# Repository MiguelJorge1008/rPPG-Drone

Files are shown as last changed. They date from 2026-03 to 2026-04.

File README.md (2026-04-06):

# Drone rPPG

Drone-based remote vital sign monitoring system (rPPG — *remote Photoplethysmography*), using the XIAO ESP32-S3 Sense as the acquisition unit and a PC as the ground station.

<p align="center">
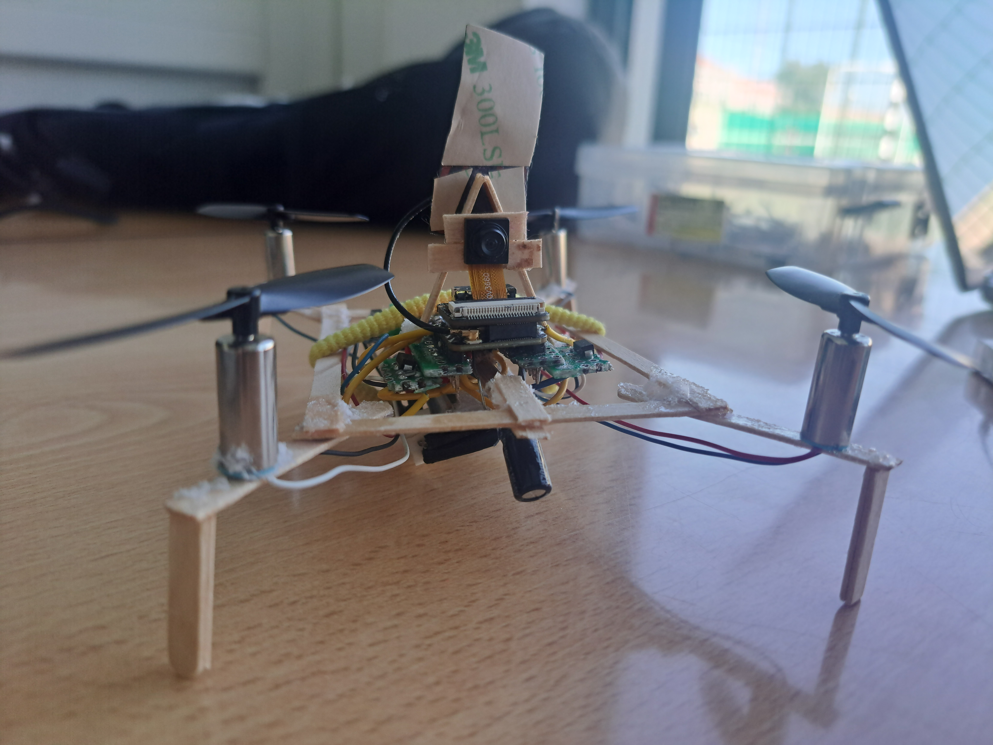
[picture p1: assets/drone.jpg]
Drone prototype
  
</p>

## Project Structure

```
Drone_rPPG/
├── firmware/                # C code (ESP-IDF) for the XIAO ESP32-S3 Sense
│   ├── main/
│   │   ├── main.c           # Wi-Fi AP, OV3660 camera, IMU, battery, HTTP/WS
│   │   ├── fc.c             # Flight controller: Mahony AHRS + cascade PID + motor mixing
│   │   ├── fc.h             # Flight controller public API
│   │   └── CMakeLists.txt
│   ├── CMakeLists.txt
│   ├── FIRMWARE.md          # Firmware technical documentation
│   ├── sdkconfig
│   └── partitions.csv
│
├── software/                # Python code (PC / Ground Station)
│   ├── main.py              # Entry point: selects mode, source, algorithm and display
│   ├── DataHandler.py       # CameraHandler, WebcamHandler, IMUHandler
│   ├── Processor.py         # FaceProcessor: forehead ROI, RGB extraction, real-time HR (rPPG)
│   ├── RespiratoryProcessor.py  # RespiratoryProcessor: pose tracking, real-time RR
│   ├── ROIExtraction.py     # Forehead ROI polygon with EMA smoothing
│   ├── SOFTWARE.md          # Software technical documentation
│   ├── algoritmos/
│   │   ├── green.py         # GREEN algorithm (Verkruysse 2008)
│   │   ├── omit.py          # OMIT algorithm (Face2PPG, Casado 2023)
│   │   ├── pos_wang.py      # POS algorithm (Wang et al. 2017)
│   │   └── adaptive_lms.py  # Adaptive LMS filter with IMU (motion cancellation)
│   └── test/
│       ├── RecordPPG.py     # Record rPPG + hardware PPG simultaneously → CSV
│       ├── RecordResp.py    # Record RR + hardware respiration sensor → CSV
│       ├── ComputeMetrics.py  # Compute HR/HRV/RR metrics → data_processed/
│       ├── Evaluate.py      # Offline evaluation: MAE±SD per algorithm
│       ├── RunTest.py       # Full pipeline: ComputeMetrics → Evaluate
│       ├── Arduino/
│       │   └── SensorIntegration.ino  # Arduino: PPG + resp sensors → Serial 115200
│       ├── data/            # Raw CSV recordings (signal only)
│       ├── data_processed/  # Processed CSVs with computed metrics
│       └── results/         # Evaluation plots (PNG)
│
├── assets/                  # Project images
└── README.md
```

## Hardware

| Component | Model | Notes |
|---|---|---|
| MCU | Seeed Studio XIAO ESP32-S3 Sense | 8 MB PSRAM + 8 MB Flash |
| Camera | OV3660 | QVGA 320×240, ~25 FPS, MJPEG |
| IMU | MPU-6050 | I2C, 500 Hz, ±16 g / ±2000°/s |
| Motors | 4× brushed DC | LEDC PWM 15 kHz, 8-bit (GPIO 2/3/4/7) |
| Battery | LiPo 1S | ADC monitoring on GPIO 1 |

## Firmware

Developed with **ESP-IDF v5.5.3**. The firmware runs on the ESP32-S3 and is responsible for:

- Creating a Wi-Fi AP network (`rPPG-Drone`, `192.168.4.1`)
- Capturing and serving the OV3660 camera **MJPEG stream** (port 81)
- Exposing IMU data and estimated attitude via **HTTP `/imu`** (port 80)
- Flight control via **flight controller** in `fc.c` (Mahony AHRS + cascade PID, 500 Hz, Core 1)
- Battery monitoring with deep sleep protection

> **Important:** AWB, AGC and AEC are **intentionally disabled**. Automatic sensor controls suppress the subtle skin color variations that make up the rPPG signal.

### Build and Flash

```bash
cd firmware
idf.py build flash monitor
```

### Flight Control

The web page at `http://192.168.4.1` includes a virtual joystick (WebSocket at 20 Hz) and ARM/DISARM buttons. See [FIRMWARE.md](firmware/FIRMWARE.md) for full details.

## Software (PC)

Developed in **Python 3.11** with OpenCV, MediaPipe and NumPy/SciPy.

| Module | Function |
|---|---|
| `main.py` | Selects mode (rPPG / Respiratory), source, algorithm and display mode at startup |
| `DataHandler.py` | `CameraHandler` (MJPEG), `WebcamHandler` (webcam), `IMUHandler` (polling `/imu`) |
| `Processor.py` | FaceMesh → forehead ROI → RGB/frame → real-time HR via peak detection (30 s window) |
| `RespiratoryProcessor.py` | Bartula 2013: chest ROI → 1D profile cross-correlation → real-time RR |
| `ROIExtraction.py` | Forehead polygon (4 landmarks) with EMA smoothing |
| `algoritmos/green.py` | Direct green channel |
| `algoritmos/omit.py` | QR decomposition, orthogonal subspace |
| `algoritmos/pos_wang.py` | 1.6 s sliding window, POS projection |
| `algoritmos/adaptive_lms.py` | Adaptive NLMS with IMU as noise reference (drone only) |
| `test/RecordPPG.py` | Simultaneous rPPG + hardware PPG recording → CSV |
| `test/RecordResp.py` | Simultaneous RR + hardware respiration sensor recording → CSV |
| `test/ComputeMetrics.py` | Post-process raw CSVs → metrics CSVs in `data_processed/` |
| `test/Evaluate.py` | MAE±SD per algorithm from `data_processed/`; plots to `results/` |
| `test/RunTest.py` | Full pipeline: ComputeMetrics → Evaluate |
| `test/Arduino/SensorIntegration.ino` | Arduino: reads PPG + respiration sensors, streams over Serial at 115200 baud |

### Run

```bash
cd software
pip install opencv-python mediapipe requests numpy scipy matplotlib pandas
python main.py
```

The program prompts for:
1. Mode: `1` rPPG · `2` Respiratory
2. Display: `1` graphs + camera window · `2` terminal only (higher FPS)
3. Video source: `A` drone · `B` webcam
4. *(rPPG only)* Algorithm: GREEN, OMIT, POS_WANG, LMS

Press `q` to stop.

| Mode | Measures | Method |
|---|---|---|
| **rPPG** | Heart rate (BPM) | FaceMesh → forehead ROI → colour signal → peak detection |
| **Respiratory** | Breathing rate (RPM) | Bartula 2013 — chest ROI cross-correlation, no landmarks |

### Record and Evaluate

<p align="center">
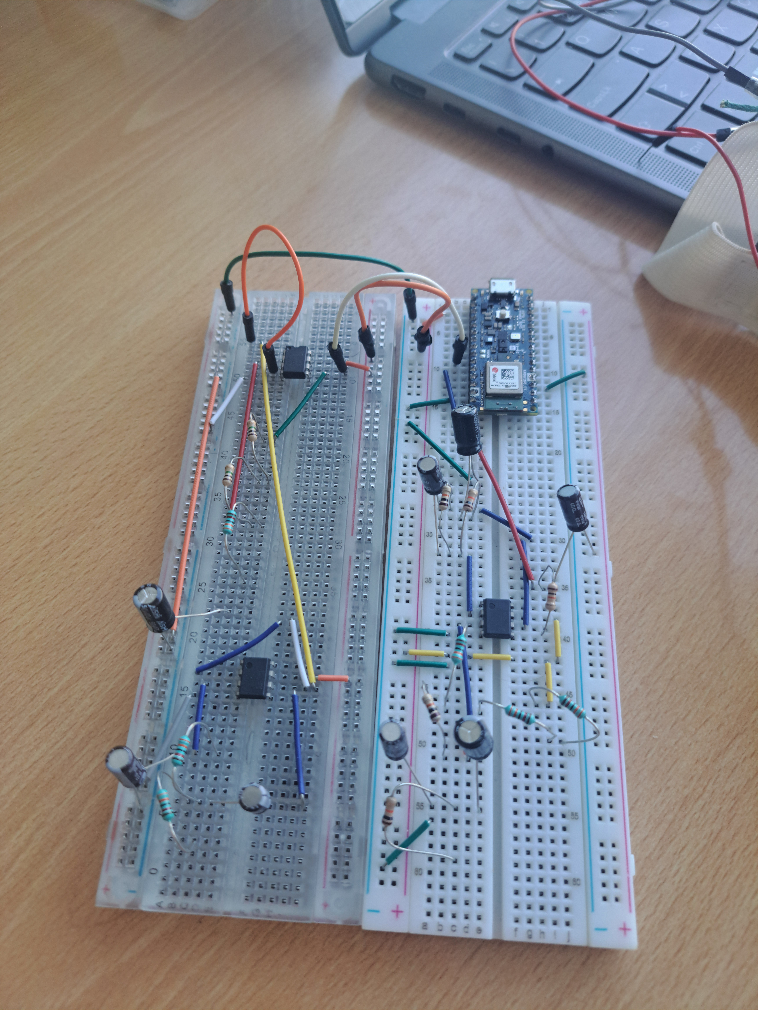
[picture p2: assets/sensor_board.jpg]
Arduino sensor board (PPG + respiration)
  
</p>

```bash
# From software/test/
python RecordPPG.py    # rPPG + hardware PPG  → data/BVP_<ALGO>_<ts>_{sw,hw}.csv
python RecordResp.py   # RR  + hardware resp  → data/RESP_<ts>_{sw,hw}.csv

# Run full evaluation pipeline
python RunTest.py
```

`RunTest.py` runs in two steps:

1. **`ComputeMetrics.py`** — reads raw signals from `data/`, computes HR/HRV/RR metrics via peak detection, writes processed CSVs to `data_processed/`
2. **`Evaluate.py`** — reads `data_processed/`, interpolates hardware GT onto software timestamps, prints per-algorithm MAE±SD tables and saves plots to `results/`

```
Table 1 — Rate: standard algorithms (MAE ± SD)
  HR:  GREEN · OMIT · POS_WANG
  RR:  BARTULA

Table 2 — Rate: motion/IMU compensation (MAE ± SD)
  GREEN (with IMU) · LMS

Table 3 — HRV + RRV: standard algorithms (MAE ± SD)
  SDNN / RMSSD (ms):  GREEN · OMIT · POS_WANG
  BBI (s):            BARTULA

Table 4 — HRV: motion/IMU compensation (MAE ± SD)
  GREEN (with IMU) · LMS
```

Tables 2 and 4 only appear when IMU/LMS recordings are present.

## How It Works

**rPPG mode (heart rate):**
```
OV3660 (MJPEG)  ──→  CameraHandler  ──→  FaceProcessor
MPU-6050        ──→  IMUHandler     ──┘
                                         │
                                    FaceMesh (468 landmarks)
                                         │
                                    Forehead ROI (4 landmarks)
                                         │
                                   Mean RGB / frame
                                         │
                              GREEN / OMIT / POS / LMS
                                         │
                              Detrend + Butterworth [0.75–4 Hz]
                                         │
                               find_peaks → BPM (30 s window)
```

**Respiratory mode (breathing rate) — Bartula et al. 2013:**
```
OV3660 (MJPEG)  ──→  CameraHandler  ──→  RespiratoryProcessor
                                         │
                                 ┌── STARTUP (once) ──┐
                                 │  MediaPipe Pose     │
                                 │  detect shoulders   │
                                 │  → chest ROI (px)  │
                                 │  close Pose         │
                                 └────────────────────┘
                                         │
                                   Fixed chest ROI
                                         │
                           1D vertical profile (mean + std / row)
                           High-pass (removes illumination drift)
                                         │
                           Phase cross-correlation (Hann window)
                           r = F⁻¹( F(pₜ) · conj(F(pₜ₋₁)) )
                           Sub-pixel peak → frame shift
                                         │
                           Integrate shifts → chest position signal
                                         │
                           Global motion detector (block-based)
                                         │
                           Detrend + Butterworth [0.1–0.5 Hz]
                                         │
                           find_peaks → breath-by-breath validation
                           (exclude motion segments, invalid durations)
                                         │
                           Median inter-breath interval → RPM
```

See [FIRMWARE.md](firmware/FIRMWARE.md) and [SOFTWARE.md](software/SOFTWARE.md) for detailed documentation.

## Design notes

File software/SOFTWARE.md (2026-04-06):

# Drone rPPG — Software

Video acquisition and face detection software for rPPG (remote Photoplethysmography) signal extraction from a drone equipped with a XIAO ESP32-S3 camera.

---

## File Structure

```
software/
├── main.py                      # Entry point: selects mode, source, algorithm and display
├── DataHandler.py               # CameraHandler, WebcamHandler, IMUHandler
├── Processor.py                 # FaceProcessor: forehead ROI, RGB extraction, real-time HR (rPPG)
├── RespiratoryProcessor.py      # RespiratoryProcessor: pose tracking, real-time RR
├── ROIExtraction.py             # Forehead polygon (4 landmarks) with EMA smoothing
├── algoritmos/
│   ├── green.py                 # GREEN algorithm (Verkruysse 2008)
│   ├── omit.py                  # OMIT algorithm (Casado 2023)
│   ├── pos_wang.py              # POS algorithm (Wang et al. 2017)
│   └── adaptive_lms.py          # Adaptive NLMS filter with IMU (drone only)
└── test/
    ├── RecordPPG.py             # Record rPPG + hardware PPG simultaneously → CSV
    ├── RecordResp.py            # Record RR + hardware respiration sensor → CSV
    ├── ComputeMetrics.py        # Post-process raw CSVs → metrics CSVs in data_processed/
    ├── Evaluate.py              # Offline evaluation: MAE±SD per algorithm; plots to results/
    ├── RunTest.py               # Runs the full pipeline: ComputeMetrics → Evaluate
    ├── Arduino/
    │   └── SensorIntegration.ino    # Arduino: PPG + respiration sensors → Serial (115200 baud)
    ├── data/                    # Raw CSV recordings (timestamp + signal only)
    ├── data_processed/          # Processed CSVs with computed metrics
    └── results/                 # Evaluation plots (PNG)
```

---

## rPPG Pipeline

```
Frame (camera / webcam)
  → MediaPipe FaceMesh (face detection)
  → Forehead ROI (4 landmarks → forehead polygon → mean RGB/frame)
  → rgb_signal (N, 3)
  → [GREEN / OMIT / POS_WANG / LMS]  →  raw BVP (N,)
  → apply_filters  →  filtered BVP (N,)
  → estimate_hr  →  BPM  (find_peaks, 30 s window)
```

---

## Files

### `main.py`

Entry point. Prompts the user for the operating mode, display preference, video source and rPPG algorithm, then starts the main loop.

**Startup prompts (in order):**

| Step | Options | Description |
|---|---|---|
| Mode | `1` rPPG · `2` Respiratory | `FaceProcessor` or `RespiratoryProcessor` |
| Display | `1` Yes · `2` No | Show matplotlib graphs + camera window, or terminal only |
| Source | `A` Drone · `B` Webcam | MJPEG stream or local webcam |
| Algorithm | `1`–`4` *(rPPG only)* | GREEN, OMIT, POS_WANG, LMS |

- **Display mode 2 (terminal only)** skips all `matplotlib` and `cv2.imshow` calls, significantly increasing FPS by eliminating rendering overhead.
- **Source A — Drone:** `CameraHandler` (MJPEG stream) + `IMUHandler` (polling `/imu`, rPPG mode only); fixed IP `http://192.168.4.1`
- **Source B — Webcam:** `WebcamHandler` (local OpenCV VideoCapture)

---

### `DataHandler.py`

Three data acquisition classes.

**Class: `CameraHandler`** — MJPEG stream from the drone camera

| Method | Description |
|---|---|
| `__init__(base_url)` | Opens the connection and starts the capture thread |
| `update()` | Continuous thread that reads the MJPEG stream, extracts JPEG frames and stores the latest one |
| `get_frame()` | Returns the latest captured frame (`None` if not yet available) |
| `stop()` | Stops the capture thread |

**Technical details:**
- Stream read via `requests` with `stream=True`
- JPEG frames extracted from the binary buffer using `0xFF 0xD8` (start) and `0xFF 0xD9` (end) markers
- Separate daemon thread with automatic reconnection (2 s retry)
- Stream URL: `http://<IP>:81/stream`

**Class: `WebcamHandler`** — local webcam (PC)

| Method | Description |
|---|---|
| `__init__()` | Opens `cv2.VideoCapture(0)` and starts capture thread |
| `get_frame()` | Returns the latest captured frame |
| `stop()` | Releases the VideoCapture |

**Class: `IMUHandler`** — drone IMU data via HTTP

| Method | Description |
|---|---|
| `__init__(base_url)` | Starts a polling thread to the `/imu` endpoint at 10 Hz |
| `get_imu()` | Returns the latest JSON sample or `None` |
| `stop()` | Stops the thread |

JSON fields: `ax, ay, az` (g), `gx, gy, gz` (°/s), `bat` (mV), `fc_state`.

---

### `ROIExtraction.py`

Forehead ROI polygon extraction with EMA smoothing.

**Constant:**

| Constant | Value | Description |
|---|---|---|
| `ROI_FOREHEAD` | `"FOREHEAD"` | 4-landmark forehead quadrilateral |

**Landmark indices:**

- `FOREHEAD_ROI = [103, 332, 296, 66]` — 4 forehead landmarks (MediaPipe FaceMesh)

**Function:**

| Function | Description |
|---|---|
| `get_roi_polygon(landmarks, w, h, ema, alpha)` | Returns forehead polygon with EMA smoothing (`alpha=0.35`) |

---

### `Processor.py`

Processes frames with MediaPipe FaceMesh, extracts the forehead RGB signal, runs rPPG algorithms and estimates HR in real time.

**Class: `FaceProcessor`**

| Method | Description |
|---|---|
| `__init__(camera, imu, algo, display)` | Initializes FaceMesh, signal buffers, background threads; `display=False` disables all rendering |
| `process_frame(frame)` | Resizes to 320×240, runs FaceMesh, extracts forehead ROI RGB, draws overlay |
| `get_fps(window=60)` | Estimates FPS from real timestamps; fallback 27.0 Hz |
| `apply_filters(bvp, fs)` | Detrend + Butterworth bandpass [0.75–4.0 Hz] |
| `estimate_hr(bvp, fs)` | `find_peaks` on filtered BVP → mean RRI → BPM |
| `_estimate_hr_realtime()` | Computes BVP + HR on last 30 s of signal |
| `_compute_hr_background()` | Background thread: HR every 30 frames |
| `run()` | Main acquisition + display loop |
| `stop()` | Closes FaceMesh and camera |

**FaceMesh configuration:**
- `max_num_faces=1`, `refine_landmarks=False`
- `min_detection_confidence=0.5`, `min_tracking_confidence=0.5`

**Filters (`apply_filters`):**

1. **Detrend** (λ=100) — removes slow baseline drift (Tarvainen sparse method)
2. **Butterworth bandpass** [0.75–4.0 Hz], order 2, `filtfilt` — cardiac band (45–240 bpm)

**HR estimation (`estimate_hr`):**

`find_peaks` with `distance=0.5 s` and `prominence=0.25×std`; RRI filter [0.4–1.5 s]; HR = 60 / mean(RRI). Consistent with `ComputeMetrics.metrics_from_peaks`.

**Background thread trigger:**

| Trigger | Interval | Task |
|---|---|---|
| Every 30 frames | ~2 s @ 15 fps | HR estimation |

---

### `RespiratoryProcessor.py`

Estimates respiratory rate (RR) in real time using the **Bartula (2013)** camera-based algorithm. Uses MediaPipe Pose **once at startup** to locate the chest and derive a tight ROI; Pose is then closed and the Bartula algorithm runs on that fixed ROI for the rest of the session.

> Bartula, M., Tigges, T., & Muehlsteff, J. *Camera-based System for Contactless Monitoring of Respiration.* IEEE EMBS, 2013.

**Class: `RespiratoryProcessor`**

| Method | Description |
|---|---|
| `__init__(camera, display)` | Initialises signal buffers, position integrator and background thread state |
| `_init_roi_from_pose(timeout)` | Runs Pose on live frames until shoulders detected; computes chest ROI; closes Pose |
| `process_frame(frame)` | Extracts profile, computes shift, integrates position, detects global motion |
| `get_fps(window=60)` | Estimates FPS from recent timestamps; fallback 25.0 Hz |
| `_make_profile(roi_gray)` | 1D vertical profile: mean+std per row, high-pass filtered |
| `_profile_shift(p_curr, p_prev)` | Phase cross-correlation with Hann window; sub-pixel quadratic interpolation |
| `_global_motion(curr, prev)` | Block-based frame-difference motion detector |
| `apply_filters(sig, fs)` | Linear detrend + Butterworth bandpass [0.1–0.5 Hz] |
| `_estimate_rr_from_peaks(filtered, fs, flags)` | Peak detection + breath-by-breath validation |
| `_compute_rr_background()` | Background thread: RR every 30 frames |
| `run()` | Calls `_init_roi_from_pose`, then main acquisition + display loop |
| `stop()` | Stops camera and closes windows |

**Bartula pipeline (per frame):**

```
Frame ROI (grayscale)
  → _make_profile       : mean(row) + std(row) → high-pass → 1D vector (H,)
  → _profile_shift      : Hann window → FFT cross-correlation → sub-pixel peak
                          r = F⁻¹( F(pₜ) · conj(F(pₜ₋₁)) )
  → integrate shift     : position += shift  (chest displacement signal)
  → _global_motion      : block diff > MOTION_THRESH → flag frame
  → apply_filters       : detrend + Butterworth [0.1–0.5 Hz]
  → _estimate_rr_from_peaks : find_peaks → validate each breath interval
                              (duration ∈ [1.5, 10] s, motion_ratio < 0.5)
  → median(valid intervals) → rpm → EMA → rr_estimate
```

**Parameters:**

| Constant | Value | Description |
|---|---|---|
| `ROI_PAD_X_FACTOR` | 0.15 | Horizontal ROI padding as fraction of shoulder width |
| `ROI_HEIGHT_FACTOR` | 1.20 | Estimated chest height as fraction of shoulder width (no hips) |
| `ROI_TOP_FACTOR` | 0.10 | ROI top margin above shoulder line |
| `HP_KERNEL` | 21 | Moving-average kernel for profile high-pass |
| `BLOCK_SIZE` | 16 px | Block size for motion detector |
| `MOTION_THRESH` | 12 | Mean abs diff threshold per block |
| `GLOBAL_MOTION_RATIO` | 0.30 | Moving-block fraction to flag global motion |
| `MIN_SEC` | 20 s | Minimum signal window before first estimate |
| `RR_ALPHA` | 0.15 | EMA smoothing factor |
| `MIN_BREATH_S` | 1.5 s | Shortest valid breath (≈ 40 rpm) |
| `MAX_BREATH_S` | 10.0 s | Longest valid breath (6 rpm) |

---

### `test/`

Hardware-synchronized recording and evaluation scripts.

**`Arduino/SensorIntegration.ino`** — Arduino sketch that reads an analog PPG sensor (pin `A6`) and a respiration sensor (pin `A5`) and streams timestamped samples over Serial at 115200 baud.

---

**`RecordPPG.py`** — Records rPPG and hardware PPG simultaneously and saves to CSV.

- **Warmup:** 30 s (no data saved); **Recording:** 60 s
- Outputs to `data/`:
  - `BVP_<ALGO>_<ts>_sw.csv` — `timestamp`, `signal_sw` (z-normalised BVP)
  - `BVP_<ALGO>_<ts>_hw.csv` — `timestamp`, `signal_hw` (raw PPG, relative time)
  - `BVP_<ALGO>_<ts>_sw_IMU.csv` / `_hw_IMU.csv` — same format, suffix `_IMU` indicates motion recording (used in Table 2 / Table 4 evaluation)
- HW signal read via Serial (Arduino, `COM3`, 115200 baud)

---

**`RecordResp.py`** — Records respiratory rate and hardware respiration sensor simultaneously and saves to CSV.

- **Warmup:** 20 s; **Recording:** 60 s
- Outputs to `data/`:
  - `RESP_<ts>_sw.csv` — `timestamp`, `signal_sw`
  - `RESP_<ts>_hw.csv` — `timestamp`, `signal_hw`

---

**`ComputeMetrics.py`** — Post-processes raw CSVs from `data/` into metric CSVs in `data_processed/`.

```bash
python ComputeMetrics.py                             # all pairs in data/
python ComputeMetrics.py --file BVP_GREEN_X_sw.csv  # single pair
```

**rPPG processing (`process_pair`):**
- SW: cumulative expanding window; `metrics_from_peaks` → HR, SDNN, RMSSD per timestamp
- HW: same, with bandpass filter [0.75–4.0 Hz] applied first
- Supports `_IMU` suffix: `BVP_<ALGO>_<ts>_sw_IMU.csv` → `BVP_<ALGO>_<ts>_sw_IMU_processed.csv`
- Outputs:
  - `BVP_<ALGO>_<ts>_sw[_IMU]_processed.csv` — `timestamp`, `signal_sw`, `HR_<algo>`, `SDNN_<algo>`, `RMSSD_<algo>`
  - `BVP_<ALGO>_<ts>_hw[_IMU]_processed.csv` — `timestamp`, `signal_hw`, `HR_gt`, `SDNN_gt`, `RMSSD_gt`

**Respiratory processing (`process_resp_pair`):**
- SW downsampled to 25 Hz before loop (avoids O(n²) at high acquisition rates)
- Sliding 30 s window; `resp_metrics_from_peaks` → RR, BBI per timestamp
- Outputs:
  - `RESP_<ts>_sw_processed.csv` — `timestamp`, `signal_sw`, `RR_BARTULA`, `BBI_BARTULA`
  - `RESP_<ts>_hw_processed.csv` — `timestamp`, `signal_hw`, `RR_gt`, `BBI_gt`

**Peak detection (`metrics_from_peaks`):**
- `find_peaks` with `distance=0.5 s`, `prominence=0.25×std`
- RRI filter: [0.4–1.5 s]; HR = 60 / mean(RRI); SDNN = std(RRI)×1000; RMSSD = √mean(ΔRRI²)×1000

**Peak detection (`resp_metrics_from_peaks`):**
- `find_peaks` with `distance=1.5 s`, `prominence=0.25×std`
- BBI filter: [1.5–10.0 s]; RR = 60 / mean(BBI)

---

**`Evaluate.py`** — Offline evaluation. Reads processed CSVs from `data_processed/`, interpolates HW ground truth onto SW timestamps, and computes MAE±SD per algorithm.

```bash
python Evaluate.py               # all recordings in data_processed/
python Evaluate.py --file BVP_GREEN_X_sw_processed.csv  # single file
```

**Warmup cutoff:**

| Recording type | Cutoff | Reason |
|---|---|---|
| rPPG (HR_*) | 30 s | Matches the 30 s minimum window in `FaceProcessor._estimate_hr_realtime` |
| Respiratory (RR_BARTULA) | 20 s | Matches `MIN_SEC = 20` in `RespiratoryProcessor` |

**GT interpolation:** HW metrics (on HW timestamps) are linearly interpolated onto SW timestamps before computing error metrics.

**Metrics:** MAE ± SD only.

**Output — four tables:**

| Table | Content |
|---|---|
| Table 1 — Rate: standard algorithms | MAE±SD for HR (GREEN, OMIT, POS_WANG) and RR (BARTULA) |
| Table 2 — Rate: motion/IMU compensation | MAE±SD for GREEN (with IMU) and LMS |
| Table 3 — HRV + RRV: standard algorithms | SDNN, RMSSD (ms) and BBI (s) MAE±SD per algorithm |
| Table 4 — HRV: motion/IMU compensation | SDNN and RMSSD MAE±SD for GREEN (with IMU) and LMS |

Tables 2 and 4 only appear when IMU/LMS recordings are present.

**Summary CSV:** `results/csv_raw/summary_metrics.csv` — all per-file results in tabular form.

**Plots:** 3-subplot figure per recording (signals + peaks, rate over time, HRV/IBI over time), cropped to 0–60 s; saved to `results/`.

---

**`RunTest.py`** — Runs the full pipeline in order:

```bash
python RunTest.py
```

1. `ComputeMetrics.py` → `data_processed/`
2. `Evaluate.py` → prints tables + saves plots to `results/`

---

**Common configuration** (top of each recording script):

| Constant | Default | Description |
|---|---|---|
| `SERIAL_PORT` | `COM3` | Serial port of the Arduino |
| `BAUD_RATE` | `115200` | Must match `SensorIntegration.ino` |
| `XIAO_IP` | `http://192.168.4.1` | Drone IP (ignored when using webcam) |
| `WARMUP_S` | 30 (PPG) / 20 (Resp) | Warmup duration before recording starts |
| `RECORD_S` | 60 | Recording duration |

---

### `algoritmos/`

Each algorithm receives `rgb (N, 3)` (and optionally `fs` or `imu`) and returns `bvp (N,)` — raw BVP signal, without filters.

#### `green.py` — GREEN

> Verkruysse, W., Svaasand, L. O. & Nelson, J. S. *Remote plethysmographic imaging using ambient light.* Optical Express 16, 21434–21445 (2008).

Extracts the green channel directly. Hemoglobin absorbs strongly in the green band (~550 nm), making it the channel with the highest pulse amplitude.

```
BVP = G
```

---

#### `omit.py` — OMIT (Orthogonal Matrix Image Transformation)

> Álvarez Casado, C., & Bordallo López, M. *Face2PPG: An unsupervised pipeline for blood volume pulse extraction from faces.* IEEE JBHI (2023).

Uses QR decomposition to remove the dominant component of the RGB signal and extract the pulse in the orthogonal subspace. Robust to video compression artifacts.

```
A = rgb.T                    # (3, N)
Q, R = qr(A)
S = Q[:, 0]                  # dominant direction
P = I - Sᵀ·S                 # orthogonal projector
Y = P @ A
BVP = Y[1, :]
```

---

#### `pos_wang.py` — POS (Plane-Orthogonal-to-Skin)

> Wang, W., den Brinker, A. C., Stuijk, S., & de Haan, G. *Algorithmic principles of remote PPG.* IEEE TBME, 64(7), 1479–1491 (2017).

1.6 s sliding window. Temporally normalizes RGB and projects onto a plane orthogonal to the skin tone to separate pulse from intensity variations.

```
l = ceil(1.6 × fs)
Cn = RGB[m:n] / mean(RGB[m:n])
S = [[0,1,-1],[-2,1,1]] @ Cn
h = S[0] + σ(S[0])/σ(S[1]) × S[1]
H[m:n] += h - mean(h)           # overlap-add
```

---

#### `adaptive_lms.py` — Adaptive LMS with IMU

> Widrow, B. & Hoff, M. E. *Adaptive switching circuits.* IRE WESCON (1960).

Cancels motion artifacts using the IMU signal as noise reference. NLMS filtering adapts its weights to estimate and subtract the motion component from the green signal.

```
green = rgb[:, 1]
imu_ref = interp(IMU, N)
error[n] = green[n] - w·x[n]
w += (μ / (||x||² + ε)) × error × x   # NLMS weight update
```

**Parameters:** `μ=0.1`, `ε=1e-3`. Drone mode only.

---

## Dependencies

```
opencv-python
mediapipe
requests
numpy
scipy
matplotlib
pandas
```

Install:
```bash
pip install opencv-python mediapipe requests numpy scipy matplotlib pandas
```

> Requires **Python 3.11** (MediaPipe has limited compatibility with newer versions)

---

## How to Run

```bash
python main.py
```

The program prompts:
1. Mode: `1` rPPG · `2` Respiratory
2. Display: `1` graphs + camera · `2` terminal only (higher FPS)
3. Video source: `A` (drone, `192.168.4.1`) or `B` (PC webcam)
4. *(rPPG only)* Algorithm: `1` GREEN · `2` OMIT · `3` POS_WANG · `4` LMS

Press `q` to stop.

### Record and evaluate

```bash
# Record (run from test/)
python RecordPPG.py    # rPPG + hardware PPG  → data/BVP_<ALGO>_<ts>_{sw,hw}.csv
python RecordResp.py   # RR  + hardware resp  → data/RESP_<ts>_{sw,hw}.csv

# Evaluate all recordings
python RunTest.py
```

---

## Status and Next Steps

- [x] MJPEG stream from XIAO ESP32 camera
- [x] Face detection with MediaPipe FaceMesh (468 landmarks)
- [x] Forehead ROI (4 landmarks, EMA-smoothed polygon)
- [x] GREEN, OMIT, POS_WANG and LMS algorithms
- [x] Filters: detrend + Butterworth bandpass [0.75–4.0 Hz]
- [x] Real-time HR via find_peaks (every 30 frames, 30 s window)
- [x] LMS motion artifact cancellation with IMU
- [x] Respiratory rate via MediaPipe Pose (thorax movement, 0.1–0.5 Hz)
- [x] Display toggle: full visual mode vs terminal-only (improved FPS)
- [x] Hardware-synchronized recording scripts (RecordPPG, RecordResp)
- [x] ComputeMetrics: peak-based HR/HRV/RR metrics → data_processed/
- [x] Evaluate: MAE±SD per algorithm, GT interpolation, plots to results/
- [x] Consistent peak-based HR estimation across real-time and offline evaluation
- [ ] IMU-based motion compensation for GREEN / OMIT / POS
- [ ] Clinical validation against oximeter ground truth

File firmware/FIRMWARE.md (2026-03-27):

# Firmware — Drone rPPG (XIAO ESP32-S3 Sense)

Firmware for MJPEG video capture over Wi-Fi with the OV3660 sensor and brushed motor flight control, optimized for **rPPG (Remote Photoplethysmography)** on a drone.

---

## Hardware

| Component | Model |
|---|---|
| MCU | Seeed Studio XIAO ESP32-S3 Sense |
| Camera | OV3660 (QQVGA 160×120, ~25 FPS, MJPEG) |
| IMU | MPU-6050 (I2C, 500 Hz, ±16 g / ±2000°/s) |
| Motors | 4× brushed DC (LEDC PWM 15 kHz, 8-bit) |
| Battery | LiPo 1S (ADC monitoring GPIO 1) |
| PSRAM | 8 MB (Octal) |
| Flash | 8 MB |
| Framework | ESP-IDF v5.5.3 |

---

## Network

The firmware operates in **Access Point (AP) mode** — the ESP32 creates its own Wi-Fi network.

| Parameter | Value |
|---|---|
| SSID | `rPPG-Drone` |
| Password | `12345678` |
| Fixed IP | `192.168.4.1` |
| Channel | 2 (2.4 GHz) |
| Security | WPA2-PSK |

---

## Quick Start

1. Build and flash:
```bash
idf.py build flash monitor
```

2. Connect your PC/phone to the `rPPG-Drone` network (password: `12345678`)

3. Open a browser at `http://192.168.4.1`

---

## HTTP Endpoints

There are **two HTTP servers**:
- **Port 80** — HTML page, controls, IMU, flight
- **Port 81** — MJPEG stream (dedicated server, does not block other endpoints)

| URL | Method | Server | Description |
|-----|---|---|---|
| `/` | GET | :80 | HTML page with stream + camera, flight and PID controls |
| `/stream` | GET | :81 | Continuous MJPEG stream |
| `/control?aec=X&gain=Y` | GET | :80 | Adjust exposure and gain at runtime |
| `/imu` | GET | :80 | JSON with raw IMU, estimated attitude, battery and FC state |
| `/cmd?state=arm\|disarm` | GET | :80 | Arm/disarm the flight controller |
| `/cmd?roll=&pitch=&yaw=&thrust=` | GET | :80 | Manual flight setpoint |
| `/pid[?att_kp=&...]` | GET | :80 | Read or update PID gains at runtime |
| `/ws` | WS | :80 | WebSocket for joystick setpoints at 20 Hz |

### `/control` Parameters

| Parameter | Range | Description |
|---|---|---|
| `aec` | 0 – 1200 | Manual exposure time (OV3660) |
| `gain` | 0 – 30 | Manual analog gain |

### `/imu` Response

```json
{
  "ax": 0.01, "ay": -0.02, "az": 0.99,
  "gx": 10.5, "gy": -5.2, "gz": 0.1,
  "roll": 1.2, "pitch": -0.8, "yaw": 45.0,
  "bat": 3850,
  "fc_state": "disarmed"
}
```

| Field | Unit | Description |
|---|---|---|
| `ax`, `ay`, `az` | g | Linear acceleration (±16 g, 2048 LSB/g) |
| `gx`, `gy`, `gz` | deg/s | Angular velocity (±2000°/s, 16.4 LSB/°/s) |
| `roll`, `pitch`, `yaw` | degrees | Attitude estimated by Mahony AHRS |
| `bat` | mV | Battery voltage (100K+100K divider, GPIO1) |
| `fc_state` | string | `"disarmed"` or `"flight"` |

### `/cmd` Parameters

| Parameter | Range | Description |
|---|---|---|
| `state` | `arm` / `disarm` | FC state transition |
| `roll` | −30 – +30 | Desired roll angle (degrees) |
| `pitch` | −30 – +30 | Desired pitch angle (degrees) |
| `yaw` | −200 – +200 | Desired yaw rate (°/s) |
| `thrust` | 0.0 – 1.0 | Normalized base thrust |

### `/pid` Parameters

GET without query → returns JSON with current gains.
GET with query → applies new gains and returns confirmed values.

| Parameter | Description | Default |
|---|---|---|
| `att_kp` | Outer loop kp (roll = pitch) | 3.5 |
| `att_ki` | Outer loop ki | 2.0 |
| `rr_kp/ki/kd` | Rate roll kp/ki/kd | 70 / 0 / 0 |
| `rp_kp/ki/kd` | Rate pitch kp/ki/kd | 70 / 0 / 0 |
| `ry_kp/ki/kd` | Rate yaw kp/ki/kd | 50 / 0 / 0 |

### WebSocket `/ws`

The client sends JSON at 20 Hz:
```json
{"r": 5.0, "p": -3.0, "y": 10.0, "t": 0.55}
```

| Field | Unit | Description |
|---|---|---|
| `r` | degrees | Roll (−30 to +30) |
| `p` | degrees | Pitch (−30 to +30) |
| `y` | °/s | Yaw rate (−200 to +200) |
| `t` | 0.0 – 1.0 | Thrust |

Each WS frame resets the FC watchdog. If no frames arrive for **500 ms**, the FC automatically transitions to `DISARMED`.

---

## Flight Controller

The flight controller is implemented in `main/fc.c` + `main/fc.h` and runs in a dedicated FreeRTOS task on **Core 1** at **500 Hz** (priority 8).

### Architecture

```
MPU-6050 (500 Hz)
    │
    ▼
Mahony AHRS  →  Euler angles (roll, pitch, yaw)
    │
    ▼
Outer PID (attitude)  →  rate setpoint
    │
    ▼
Inner PID (rate)  →  torques (roll, pitch, yaw)
    │
    ▼
Motor mixing  →  M1/M2/M3/M4 duties (0–255)
```

**Sensor fusion:** Mahony AHRS (ported from `sensfusion6.c` — Crazyflie / ESP-Drone).
**PID:** Cascade rate/attitude (ported from `pid.c` — Crazyflie / ESP-Drone).

### FC States

| State | Description |
|---|---|
| `FC_DISARMED` | Motors off, PIDs reset |
| `FC_FLIGHT` | PID active, accepts setpoints via `/cmd` or `/ws` |

### Safety

| Mechanism | Value | Behavior |
|---|---|---|
| Setpoint watchdog | 500 ms | FC transitions to DISARMED if no setpoint received |
| Tilt protection | ±50° | FC transitions to DISARMED if roll or pitch exceeds limit |
| Mahony warmup | 2 s | Motors locked at boot for AHRS convergence |
| Critical battery | < 3100 mV | FC transitions to DISARMED + deep sleep |

### Motor Mixing (quadrotor X)

```
M1 (front-left, CW)  |  M2 (front-right, CCW)
─────────────────────────────────────────────
M4 (back-left, CCW)  |  M3 (back-right, CW)
```

| Motor | GPIO | Rotation | LEDC Channel |
|---|---|---|---|
| M1 (front-left) | GPIO 2 | CW | CH1 |
| M2 (front-right) | GPIO 3 | CCW | CH2 |
| M3 (back-right) | GPIO 4 | CW | CH3 |
| M4 (back-left) | GPIO 7 | CCW | CH4 |

**LEDC:** Timer 1, 15 kHz, 8-bit (0–255). Timer 0 / Channel 0 is reserved for the camera XCLK.

---

## Battery

| Parameter | Value |
|---|---|
| ADC Pin | GPIO 1 (ADC1 CH0) |
| Voltage divider | 100 kΩ + 100 kΩ (factor ×2) |
| Warning | < 3500 mV |
| Critical / deep sleep | < 3100 mV |
| No battery | < 2000 mV (alarm ignored) |
| Status LED | GPIO 21 |

When battery enters critical: FC transitions to DISARMED → LED blinks 10× → `esp_deep_sleep_start()`.

---

## OV3660 Sensor Configuration for rPPG

### Why Disable Automatic Controls

For rPPG it is **mandatory** to disable all automatic sensor controls. If active, the sensor continuously compensates for brightness variations in the skin — which is precisely the signal being captured.

| Control | Disabled function | Reason |
|---|---|---|
| AWB (Auto White Balance) | `set_whitebal(s, 0)` | Would re-balance R/G/B channels frame by frame |
| AGC (Auto Gain Control) | `set_gain_ctrl(s, 0)` | Gain variations introduce artifacts in the PPG signal |
| AEC (Auto Exposure) | `set_exposure_ctrl(s, 0)` | AEC compensates exactly the skin reflectance variations |
| AEC nightmode | `set_aec2(s, 0)` | Extra DSP mode of AEC, equally harmful |

### Calibrated Default Values

```c
s->set_agc_gain(s, 3);        // Fixed gain
s->set_aec_value(s, 1200);    // Fixed exposure — adjustable at runtime via /control
```

| Condition | Recommended aec | gain |
|---|---|---|
| Outdoors — direct sunlight | 20 – 60 | 0 – 2 |
| Outdoors — overcast | 100 – 200 | 2 – 4 |
| Indoors (testing) | 400 – 800 | 4 – 8 |

### Green Cast — Expected Behavior

With AWB disabled, the image shows a **pronounced green cast**. This is normal:
- The OV3660 sensor uses **RGGB** Bayer pattern — 2 green pixels per 1 red and 1 blue
- Without automatic color correction, green dominates (raw sensor response)
- The green channel is the **most sensitive to the PPG signal** (~550 nm)
- Most rPPG algorithms (GREEN, CHROM, POS) extract the signal primarily from the green channel

### Indoor Lighting Flicker

In indoor environments with LED/fluorescent lighting, periodic brightness variations may appear. This is due to the mains frequency (100 Hz in Europe / 50 Hz AC).

- If variation occurs in non-skin areas → it is lighting flicker
- If variation occurs mainly in skin periodically (~60–80 bpm) → it is the rPPG signal

In outdoor sunlight this problem does not exist.

---

## Performance

| Parameter | Value |
|---|---|
| Resolution | **QQVGA (160×120)** |
| Average FPS | **~25 FPS** (dependent on Wi-Fi conditions) |
| JPEG quality | 8 |
| Frame buffers | 3 in PSRAM (`CAMERA_GRAB_LATEST`) |
| XCLK | 24 MHz |
| Serial log | `>>> STREAMING: XX.XX FPS \| Res: QQVGA` (every second) |

---

## HTTP Server

```c
/* Port 80 — page + controls */
server_config.stack_size       = 8192;
server_config.max_uri_handlers = 10;
server_config.max_open_sockets = 7;

/* Port 81 — MJPEG stream */
stream_config.stack_size       = 8192;
stream_config.max_uri_handlers = 2;
stream_config.max_open_sockets = 2;
```

The MJPEG stream runs on a separate server (port 81) so that requests to `/control`, `/imu`, `/cmd`, etc. are never blocked by the persistent TCP socket of the stream.

The HTML page pauses the stream before sending the `/control` request and reconnects 200 ms later — prevents image freezing due to socket contention.

---

## Pin Mapping (XIAO ESP32-S3 Sense)

### Camera (OV3660)

| Signal | GPIO |
|---|---|
| XCLK | 10 |
| SDA (SCCB) | 40 |
| SCL (SCCB) | 39 |
| D0–D7 | 15, 17, 18, 16, 14, 12, 11, 48 |
| VSYNC | 38 |
| HREF | 47 |
| PCLK | 13 |
| PWDN / RESET | N/A (-1) |

### IMU (MPU-6050)

| Signal | GPIO |
|---|---|
| SCL (I2C) | 5 |
| SDA (I2C) | 6 |
| I2C Address | 0x68 |
| Sample rate | 500 Hz |
| Gyro full-scale | ±2000°/s (16.4 LSB/°/s) |
| Accel full-scale | ±16 g (2048 LSB/g) |

### Motors (LEDC PWM)

| Signal | GPIO |
|---|---|
| M1 (front-left, CW) | 2 |
| M2 (front-right, CCW) | 3 |
| M3 (back-right, CW) | 4 |
| M4 (back-left, CCW) | 7 |

### Other

| Signal | GPIO |
|---|---|
| Battery ADC | 1 (ADC1 CH0) |
| Status LED | 21 |

---

## Troubleshooting

**Browser only shows the stream without controls**
→ Old version cached. Press Ctrl+Shift+R or open in incognito mode.

**Stream not appearing (`http://192.168.4.1`)**
→ The stream is on port 81. The HTML page points to `http://192.168.4.1:81/stream`. Check if the second server started in the serial logs.

**Compile time in serial monitor is old**
→ Firmware was not reflashed. Run `idf.py build flash monitor`.

**Camera controls do not change the image**
→ The JS pauses the stream, sends `/control`, reconnects. Check serial logs: `Control: OK | aec=X gain=Y`.

**Forehead overexposed / saturated**
→ Reduce `aec` via slider. For outdoor sunlight, use aec < 60.

**`rPPG-Drone` network not appearing**
→ Check serial monitor: `AP started: rPPG-Drone | 192.168.4.1`. If not shown, reflash.

**FC does not arm (ARM button has no effect)**
→ Wait 2 s after boot (Mahony warmup). Check that MPU-6050 initialized without error in serial logs.

**FC disarms during flight**
→ May be watchdog (no setpoints for more than 500 ms) or tilt protection (tilt > 50°). Check serial logs: `WDT timeout` or `TILT PROTECTION`.

**No internet access while connected to ESP32**
→ Expected behavior — the ESP32 AP does not provide internet. Prepare everything before switching networks.

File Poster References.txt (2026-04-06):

[1]	World Health Organization, ‘Global health estimates: Leading causes of death’. Accessed: Apr. 06, 2026. [Online]. Available: https://www.who.int/data/gho/data/themes/mortality-and-global-health-estimates/ghe-leading-causes-of-death
[2]	U. Debnath and S. Kim, ‘A comprehensive review of heart rate measurement using remote photoplethysmography and deep learning’, Biomed. Eng. OnLine, vol. 24, no. 1, p. 73, Jun. 2025, doi: 10.1186/s12938-025-01405-5.
[3]	S. Sakib, Z. Hasan, and N. Roy, ‘A State-Of-The-Art Survey of Remote Photoplethysmography for Contactless Health Parameters Sensing’, WIREs Data Min. Knowl. Discov., vol. 15, no. 3, p. e70039, 2025, doi: 10.1002/widm.70039.

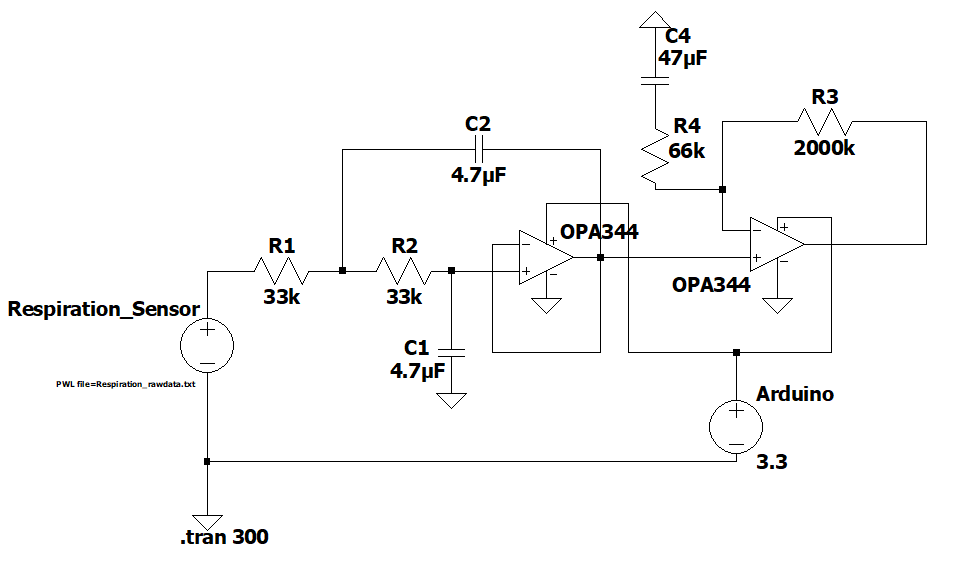
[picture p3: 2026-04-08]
hardware/Respiration Ground Truth Filter.png

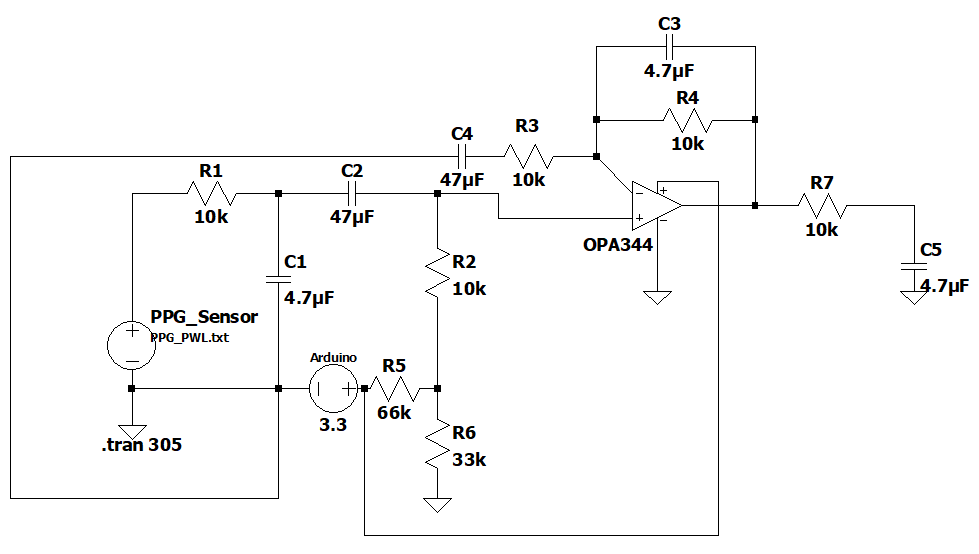
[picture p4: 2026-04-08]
hardware/PPG Ground Truth Filter.png

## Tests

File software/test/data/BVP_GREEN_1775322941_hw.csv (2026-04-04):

timestamp | signal_hw
0.0 | 0.044
0.003995180130004883 | 0.0342
0.028997421264648438 | 0.0244
0.04727792739868164 | 0.0147
0.07582902908325195 | 0.0098
0.09283590316772461 | 0.0098
0.11205863952636719 | 0.132
0.14239954948425293 | 0.4008
0.1584007740020752 | 0.7869
0.18140625953674316 | 1.1486
0.19695568084716797 | 1.4614
0.22602152824401855 | 1.6667
0.2465648651123047 | 1.7546
0.2625694274902344 | 1.7155
0.28058362007141113 | 1.5836
0.5030405521392822 | 1.3539
0.5040433406829834 | 1.1095
0.5050420761108398 | 0.8553
0.5050420761108398 | 0.6452
0.50604248046875 | 0.4985
0.50604248046875 | 0.3861
0.5070428848266602 | 0.3226
0.5070428848266602 | 0.2835
0.508040189743042 | 0.2346
0.508040189743042 | 0.176
0.5170762538909912 | 0.1173
0.5370500087738037 | 0.0684
0.5655341148376465 | 0.0489
0.5815377235412598 | 0.0293
0.6010844707489014 | 0.0244
0.6321797370910645 | 0.0147
0.6470789909362793 | 0.0098
0.6650774478912354 | 0.0049
0.6961045265197754 | 0.0049
0.7106516361236572 | 0.0
0.7296304702758789 | 0.0
0.7576711177825928 | 0.0049
0.7782535552978516 | 0.0098
0.7942397594451904 | 0.0
0.8137695789337158 | 0.0049
0.8427698612213135 | 0.0
0.8591716289520264 | 0.0
0.8771672248840332 | 0.0
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

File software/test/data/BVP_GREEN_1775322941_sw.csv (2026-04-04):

timestamp | signal_sw
1.1194884777069092 | 0.13694879185061437
1.1344785690307617 | 0.3031491810403235
1.1524817943572998 | 0.46747574931280217
1.1674957275390625 | 0.626492798703578
1.1855573654174805 | 0.7767586709470863
1.2015409469604492 | 0.9150377293934189
1.2215478420257568 | 1.0384745883040176
1.2375478744506836 | 1.144677949474327
1.2545561790466309 | 1.2317419566302745
1.271225929260254 | 1.2982242709365976
1.2892239093780518 | 1.3430728762155104
1.3042263984680176 | 1.3655499506296327
1.320230484008789 | 1.3652459200817357
1.3382244110107422 | 1.3421686983373846
1.3532614707946777 | 1.2967987863299855
1.3721511363983154 | 1.230081481313499
1.389366865158081 | 1.1434221577375316
1.408372402191162 | 1.0387266284748373
1.424375295639038 | 0.9184468163735249
1.4396543502807617 | 0.7855716085911476
1.4566357135772705 | 0.6435313892830057
1.4741804599761963 | 0.4960064400075242
1.4891791343688965 | 0.34670790491093506
1.5031790733337402 | 0.19924908323649376
1.5247576236724854 | 0.05710856003973041
1.5410261154174805 | -0.07645250149479733
1.5601072311401367 | -0.19857024285961983
1.5779237747192383 | -0.30694202087413414
1.5939505100250244 | -0.3999264456386817
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

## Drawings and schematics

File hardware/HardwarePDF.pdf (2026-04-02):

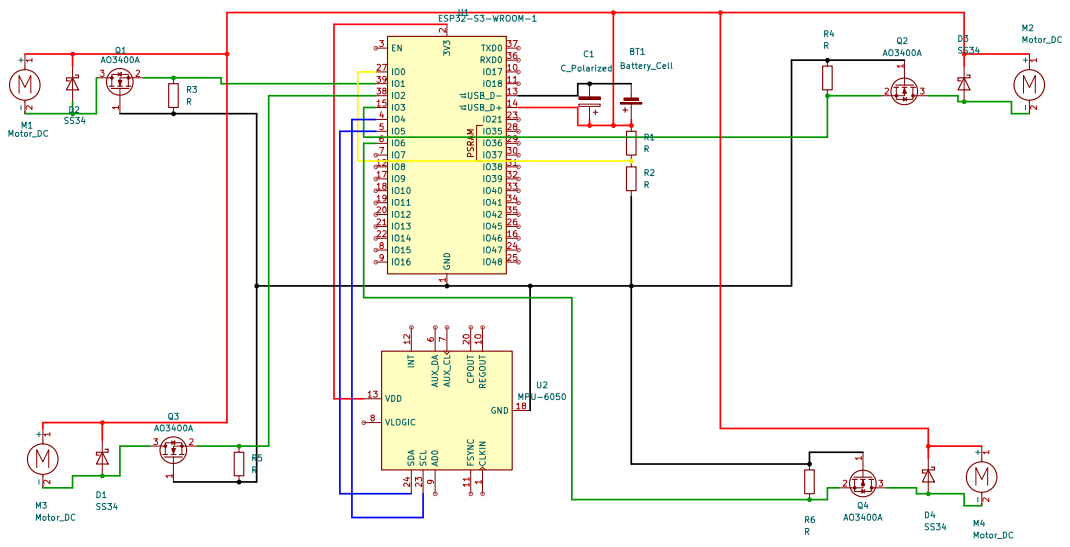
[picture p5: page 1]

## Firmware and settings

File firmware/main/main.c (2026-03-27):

#include <esp_system.h>
#include <nvs_flash.h>
#include <sys/param.h>
#include <string.h>
#include <stdlib.h>
#include "esp_timer.h"
#include "esp_camera.h"
#include "esp_wifi.h"
#include "esp_event.h"
#include "esp_log.h"
#include "esp_http_server.h"
#include "esp_adc/adc_oneshot.h"
#include "esp_adc/adc_cali.h"
#include "esp_adc/adc_cali_scheme.h"
#include "driver/gpio.h"
#include "esp_sleep.h"
#include "freertos/FreeRTOS.h"
#include "freertos/task.h"
#include "freertos/semphr.h"

#include "fc.h"

static const char *TAG = "XIAO_S3_DRONE";

/* ==========================================================
   BATTERY
   ========================================================== */
#define BAT_ADC_CHANNEL   ADC_CHANNEL_0   // GPIO 1 (D0)
#define BAT_WARN_MV       3500
#define BAT_CRITICAL_MV   3000
#define LED_GPIO          GPIO_NUM_21

static adc_oneshot_unit_handle_t adc1_handle;
static adc_cali_handle_t adc_cali_handle = NULL;

static void bat_adc_init(void) {
    adc_oneshot_unit_init_cfg_t init_cfg = { .unit_id = ADC_UNIT_1 };
    adc_oneshot_new_unit(&init_cfg, &adc1_handle);

    adc_oneshot_chan_cfg_t chan_cfg = {
        .atten    = ADC_ATTEN_DB_12,
        .bitwidth = ADC_BITWIDTH_12,
    };
    adc_oneshot_config_channel(adc1_handle, BAT_ADC_CHANNEL, &chan_cfg);

    adc_cali_curve_fitting_config_t cali_cfg = {
        .unit_id  = ADC_UNIT_1,
        .chan     = BAT_ADC_CHANNEL,
        .atten    = ADC_ATTEN_DB_12,
        .bitwidth = ADC_BITWIDTH_12,
    };
    if (adc_cali_create_scheme_curve_fitting(&cali_cfg, &adc_cali_handle) != ESP_OK) {
        ESP_LOGW(TAG, "ADC calibration unavailable");
        adc_cali_handle = NULL;
    }

    gpio_config_t led_cfg = {
        .pin_bit_mask = (1ULL << LED_GPIO),
        .mode         = GPIO_MODE_OUTPUT,
    };
    gpio_config(&led_cfg);
    gpio_set_level(LED_GPIO, 0);
}

static int bat_read_mv(void) {
    int sum = 0;
    for (int i = 0; i < 8; i++) {
        int raw = 0;
        adc_oneshot_read(adc1_handle, BAT_ADC_CHANNEL, &raw);
        int voltage_mv = 0;
        if (adc_cali_handle) {
            adc_cali_raw_to_voltage(adc_cali_handle, raw, &voltage_mv);
        } else {
            voltage_mv = (int)((raw / 4095.0f) * 3100.0f);
        }
        sum += voltage_mv;
    }
    return (sum / 8) * 2; // average of 8 readings, 100K+100K voltage divider
}

static void battery_task(void *arg) {
    int critical_count = 0;
    while (1) {
        int mv = bat_read_mv();
        ESP_LOGI(TAG, "Battery: %d mV", mv);

        if (mv < 2000) {
            ESP_LOGI(TAG, "No battery detected (%d mV)", mv);
            critical_count = 0;
        } else if (mv < BAT_CRITICAL_MV) {
            critical_count++;
            ESP_LOGW(TAG, "Low battery (%d mV) %d/3", mv, critical_count);
            if (critical_count >= 3) {
                ESP_LOGW(TAG, "Critical battery! Entering deep sleep...");
                fc_set_state(FC_DISARMED);
                for (int i = 0; i < 10; i++) {
                    gpio_set_level(LED_GPIO, i % 2);
                    vTaskDelay(pdMS_TO_TICKS(100));
                }
                gpio_set_level(LED_GPIO, 0);
                esp_deep_sleep_start();
            }
        } else if (mv < BAT_WARN_MV) {
            critical_count = 0;
            for (int i = 0; i < 6; i++) {
                gpio_set_level(LED_GPIO, i % 2);
                vTaskDelay(pdMS_TO_TICKS(150));
            }
        } else {
            critical_count = 0;
            gpio_set_level(LED_GPIO, 0);
        }

        vTaskDelay(pdMS_TO_TICKS(10000));
    }
}

/* ==========================================================
   WI-FI CONFIGURATION
   ========================================================== */
#define WIFI_SSID      "rPPG-Drone"
#define WIFI_PASS      "12345678"

/* ==========================================================
   XIAO ESP32-S3 CAMERA GPIO MAPPING
   ========================================================== */
#define PWDN_GPIO_NUM  -1
#define RESET_GPIO_NUM -1
#define XCLK_GPIO_NUM  10
#define SIOD_GPIO_NUM  40
#define SIOC_GPIO_NUM  39

#define Y9_GPIO_NUM    48
#define Y8_GPIO_NUM    11
#define Y7_GPIO_NUM    12
#define Y6_GPIO_NUM    14
#define Y5_GPIO_NUM    16
#define Y4_GPIO_NUM    18
#define Y3_GPIO_NUM    17
#define Y2_GPIO_NUM    15

#define VSYNC_GPIO_NUM 38
#define HREF_GPIO_NUM  47
#define PCLK_GPIO_NUM  13

/* MJPEG boundary */
#define PART_BOUNDARY "123456789000000000000987654321"
static const char* _STREAM_CONTENT_TYPE = "multipart/x-mixed-replace;boundary=" PART_BOUNDARY;
static const char* _STREAM_BOUNDARY = "\r\n--" PART_BOUNDARY "\r\n";
static const char* _STREAM_PART = "Content-Type: image/jpeg\r\nContent-Length: %u\r\n\r\n";

/* ==========================================================
   HTML PAGE
   ========================================================== */
static const char INDEX_HTML[] =
"<!DOCTYPE html><html><head>"
"<meta charset='utf-8'>"
"<meta name='viewport' content='width=device-width,initial-scale=1'>"
"<title>rPPG Drone</title>"
"</head><body style='background:#111;color:#eee;font-family:monospace;text-align:center;padding:10px'>"
"<h3 style='margin:4px 0'>rPPG Drone Control</h3>"

/* ── Camera controls ── */
"<p style='margin:6px 0 2px'>AEC (0-1200): <b id='va'>1200</b></p>"
"<input type='range' min='0' max='1200' value='1200' style='width:80%' "
"oninput=\"document.getElementById('va').innerText=this.value;aecVal=this.value\">"
"<p style='margin:6px 0 2px'>Gain (0-30): <b id='vg'>3</b></p>"
"<input type='range' min='0' max='30' value='3' style='width:80%' "
"oninput=\"document.getElementById('vg').innerText=this.value;gainVal=this.value\">"
"<button onclick='sendCam()' style='display:block;margin:8px auto;padding:8px 28px;background:#1a7a1a;color:#fff;border:none;font-size:14px;cursor:pointer'>Apply Camera</button>"
"<p id='st' style='color:#aaa;font-size:11px;margin:2px 0 6px'></p>"

/* ── Stream ── */
"<img id='si' src='http://192.168.4.1:81/stream' style='max-width:100%;display:block;margin:0 auto;border:1px solid #444'>"

/* ── IMU / Attitude ── */
"<div style='margin:10px auto;max-width:400px;background:#1e1e1e;border:1px solid #333;padding:8px;text-align:left;font-size:12px'>"
"<b>IMU</b> &nbsp;<span id='imu_err' style='color:#f66'></span><br>"
"Accel: X=<span id='ax'>-</span>g Y=<span id='ay'>-</span>g Z=<span id='az'>-</span>g<br>"
"Gyro: X=<span id='gx'>-</span> Y=<span id='gy'>-</span> Z=<span id='gz'>-</span> deg/s<br>"
"<b>Attitude:</b> Roll=<span id='att_r'>-</span>&deg; Pitch=<span id='att_p'>-</span>&deg; Yaw=<span id='att_y'>-</span>&deg;<br>"
"<b>Battery:</b> <span id='bat'>-</span> mV"
"</div>"

/* ── Flight controls ── */
"<div style='margin:10px auto;max-width:400px;background:#1e1e1e;border:1px solid #333;padding:8px;font-size:12px'>"
"<b>Flight Control</b><br>"
"State: <b id='fc_state' style='color:#ff0'>DISARMED</b><br><br>"
"<button onclick='fcCmd(\"state=arm\")' style='padding:6px 16px;background:#7a1a1a;color:#fff;border:none;cursor:pointer;margin:3px'>ARM</button>"
"<button onclick='fcCmd(\"state=disarm\")' style='padding:6px 16px;background:#444;color:#fff;border:none;cursor:pointer;margin:3px'>DISARM</button>"
"<p style='color:#666;font-size:10px;margin:4px 0'>ARM enables manual /cmd?roll=&amp;pitch=&amp;yaw=&amp;thrust=</p>"
"</div>"

/* ── Joystick ── */
"<div style='margin:10px auto;max-width:400px'>"
"<div style='display:flex;justify-content:space-around;align-items:center'>"
"<div style='text-align:center'>"
"<p style='margin:2px;font-size:10px;color:#aaa'>Thrust / Yaw</p>"
"<canvas id='lj' width='130' height='130' style='border:2px solid #555;border-radius:50%;background:#1a1a1a;touch-action:none'></canvas>"
"</div>"
"<div style='text-align:center'>"
"<p style='margin:2px;font-size:10px;color:#aaa'>Pitch / Roll</p>"
"<canvas id='rj' width='130' height='130' style='border:2px solid #555;border-radius:50%;background:#1a1a1a;touch-action:none'></canvas>"
"</div>"
"</div>"
"<p id='ws_st' style='font-size:10px;color:#f66;margin:4px 0;text-align:center'>WS desligado</p>"
"</div>"

/* ── PID tuning ── */
"<div style='margin:10px auto;max-width:400px;background:#1e1e1e;border:1px solid #333;padding:8px;font-size:11px;text-align:left'>"
"<b>PID Tuning</b> <button onclick='loadPid()' style='float:right;padding:2px 8px;font-size:10px;background:#333;color:#eee;border:1px solid #555;cursor:pointer'>Load</button><br><br>"
"Att kp:<input id='att_kp' style='width:55px;background:#111;color:#eee;border:1px solid #444;margin:2px' value='3.5'> "
"ki:<input id='att_ki' style='width:55px;background:#111;color:#eee;border:1px solid #444;margin:2px' value='2.0'><br>"
"Rate R kp:<input id='rr_kp' style='width:50px;background:#111;color:#eee;border:1px solid #444;margin:2px' value='70'> "
"ki:<input id='rr_ki' style='width:45px;background:#111;color:#eee;border:1px solid #444;margin:2px' value='0'> "
"kd:<input id='rr_kd' style='width:45px;background:#111;color:#eee;border:1px solid #444;margin:2px' value='0'><br>"
"Rate P kp:<input id='rp_kp' style='width:50px;background:#111;color:#eee;border:1px solid #444;margin:2px' value='70'> "
"ki:<input id='rp_ki' style='width:45px;background:#111;color:#eee;border:1px solid #444;margin:2px' value='0'> "
"kd:<input id='rp_kd' style='width:45px;background:#111;color:#eee;border:1px solid #444;margin:2px' value='0'><br>"
"Rate Y kp:<input id='ry_kp' style='width:50px;background:#111;color:#eee;border:1px solid #444;margin:2px' value='50'> "
"ki:<input id='ry_ki' style='width:45px;background:#111;color:#eee;border:1px solid #444;margin:2px' value='0'> "
"kd:<input id='ry_kd' style='width:45px;background:#111;color:#eee;border:1px solid #444;margin:2px' value='0'><br>"
"<button onclick='applyPid()' style='margin-top:6px;padding:4px 16px;background:#1a4a7a;color:#fff;border:none;cursor:pointer'>Apply PID</button>"
"<span id='pid_st' style='color:#aaa;font-size:10px;margin-left:8px'></span>"
"</div>"

/* ── Scripts ── */
"<script>"
"var aecVal=1200,gainVal=3;"
"function sendCam(){"
"var img=document.getElementById('si');"
"img.src='';"
"var x=new XMLHttpRequest();"
"x.open('GET','/control?aec='+aecVal+'&gain='+gainVal);"
"x.onload=function(){"
"document.getElementById('st').innerText=x.responseText;"
"setTimeout(function(){img.src='http://192.168.4.1:81/stream?t='+Date.now();},200);};"
"x.onerror=function(){document.getElementById('st').innerText='Error';"
"img.src='http://192.168.4.1:81/stream';};"
"x.send();}"

"function fcCmd(q){"
"var x=new XMLHttpRequest();"
"x.open('GET','/cmd?'+q);"
"x.onload=function(){"
"try{"
"var d=JSON.parse(x.responseText);"
"document.getElementById('fc_state').innerText=d.state.toUpperCase();"
"}catch(e){}"
"};"
"x.send();}"


"function updateImu(){"
"var x=new XMLHttpRequest();"
"x.open('GET','/imu');"
"x.onload=function(){"
"try{"
"var d=JSON.parse(x.responseText);"
"document.getElementById('ax').innerText=d.ax.toFixed(2);"
"document.getElementById('ay').innerText=d.ay.toFixed(2);"
"document.getElementById('az').innerText=d.az.toFixed(2);"
"document.getElementById('gx').innerText=d.gx.toFixed(1);"
"document.getElementById('gy').innerText=d.gy.toFixed(1);"
"document.getElementById('gz').innerText=d.gz.toFixed(1);"
"document.getElementById('att_r').innerText=d.roll.toFixed(1);"
"document.getElementById('att_p').innerText=d.pitch.toFixed(1);"
"document.getElementById('att_y').innerText=d.yaw.toFixed(1);"
"document.getElementById('bat').innerText=d.bat;"
"var states={'disarmed':'DISARMED','flight':'FLIGHT','hover':'HOVER+rPPG'};"
"if(d.fc_state) document.getElementById('fc_state').innerText=states[d.fc_state]||d.fc_state.toUpperCase();"
"document.getElementById('imu_err').innerText='';"
"}catch(e){document.getElementById('imu_err').innerText='error';}};"
"x.onerror=function(){document.getElementById('imu_err').innerText='offline';};"
"x.send();}"
"setInterval(updateImu,500);"
"updateImu();"

/* WebSocket + Joystick JS */
"var ws=null,wsOk=false;"
"var lx=0,ly=0.5,rx=0,ry=0;"  /* ly=0.5 → thrust começa a 50% */

"function wsConn(){"
"ws=new WebSocket('ws://192.168.4.1/ws');"
"ws.onopen=function(){wsOk=true;document.getElementById('ws_st').style.color='#4a4';document.getElementById('ws_st').innerText='WS ligado';};"
"ws.onclose=function(){wsOk=false;document.getElementById('ws_st').style.color='#f66';document.getElementById('ws_st').innerText='WS desligado';setTimeout(wsConn,2000);};"
"ws.onerror=function(){ws.close();};"
"}"
"wsConn();"

/* Envia setpoint a 20 Hz via WebSocket */
"setInterval(function(){"
"if(wsOk&&ws.readyState===1){"
"var r=(rx*30).toFixed(1);"
"var p=(-ry*30).toFixed(1);"
"var y=(lx*200).toFixed(1);"
"var t=((ly+1)/2).toFixed(2);"  /* [-1,1] → [0,1] */
"ws.send('{\"r\":'+r+',\"p\":'+p+',\"y\":'+y+',\"t\":'+t+'}');"
"}},50);"

/* Joystick helper */
"function mkJoy(id,isLeft){"
"var c=document.getElementById(id),ctx=c.getContext('2d');"
"var R=c.width/2,r=R-8,tx=R,ty=R,act=false;"
"function draw(){"
"ctx.clearRect(0,0,c.width,c.height);"
"ctx.beginPath();ctx.arc(R,R,r,0,6.28);ctx.strokeStyle='#555';ctx.lineWidth=1;ctx.stroke();"
"ctx.beginPath();ctx.arc(R,R,2,0,6.28);ctx.fillStyle='#555';ctx.fill();"
"ctx.beginPath();ctx.arc(tx,ty,18,0,6.28);ctx.fillStyle=wsOk?'#4a4':'#555';ctx.fill();}"
"function pos(ex,ey){"
"var rc=c.getBoundingClientRect(),px=ex-rc.left-R,py=ey-rc.top-R;"
"var d=Math.sqrt(px*px+py*py);if(d>r){px=px/d*r;py=py/d*r;}"
"tx=R+px;ty=R+py;"
"if(isLeft){lx=px/r;ly=-(py/r);}else{rx=px/r;ry=py/r;}"
"draw();}"
"c.addEventListener('touchstart',function(e){e.preventDefault();act=true;pos(e.touches[0].clientX,e.touches[0].clientY);},{passive:false});"
"c.addEventListener('touchmove',function(e){e.preventDefault();if(act)pos(e.touches[0].clientX,e.touches[0].clientY);},{passive:false});"
"c.addEventListener('touchend',function(e){e.preventDefault();act=false;"
"if(isLeft){lx=0;tx=R;ty=R-ly*r;}"  /* yaw centra, thrust mantém */
"else{rx=0;ry=0;tx=R;ty=R;}"         /* pitch/roll centram */
"draw();},{passive:false});"
"setInterval(draw,200);"  /* redraw periódico para atualizar cor WS */
"draw();}"
"mkJoy('lj',true);mkJoy('rj',false);"

/* PID tuning */
"function loadPid(){"
"fetch('/pid').then(function(r){return r.json();}).then(function(d){"
"document.getElementById('att_kp').value=d.att_kp;"
"document.getElementById('att_ki').value=d.att_ki;"
"document.getElementById('rr_kp').value=d.rr_kp;"
"document.getElementById('rr_ki').value=d.rr_ki;"
"document.getElementById('rr_kd').value=d.rr_kd;"
"document.getElementById('rp_kp').value=d.rp_kp;"
"document.getElementById('rp_ki').value=d.rp_ki;"
"document.getElementById('rp_kd').value=d.rp_kd;"
"document.getElementById('ry_kp').value=d.ry_kp;"
"document.getElementById('ry_ki').value=d.ry_ki;"
"document.getElementById('ry_kd').value=d.ry_kd;"
"document.getElementById('pid_st').innerText='OK';});}"

"function applyPid(){"
"var q='att_kp='+document.getElementById('att_kp').value"
"+'&att_ki='+document.getElementById('att_ki').value"
"+'&rr_kp='+document.getElementById('rr_kp').value"
"+'&rr_ki='+document.getElementById('rr_ki').value"
"+'&rr_kd='+document.getElementById('rr_kd').value"
"+'&rp_kp='+document.getElementById('rp_kp').value"
"+'&rp_ki='+document.getElementById('rp_ki').value"
"+'&rp_kd='+document.getElementById('rp_kd').value"
"+'&ry_kp='+document.getElementById('ry_kp').value"
"+'&ry_ki='+document.getElementById('ry_ki').value"
"+'&ry_kd='+document.getElementById('ry_kd').value;"
"fetch('/pid?'+q).then(function(){document.getElementById('pid_st').innerText='Applied';});}"

"</script>"
"</body></html>";

/* ==========================================================
   HTTP HANDLERS
   ========================================================== */

/* GET /imu — IMU raw + attitude + battery JSON */
esp_err_t imu_handler(httpd_req_t *req) {
    char buf[220];
    int bat = bat_read_mv();

    fc_imu_t imu;
    fc_get_imu(&imu);

    float roll, pitch, yaw;
    fc_get_attitude(&roll, &pitch, &yaw);

    const char *state_str =
        fc_get_state() == FC_DISARMED      ? "disarmed" :
        fc_get_state() == FC_FLIGHT        ? "flight"   : "hover";

    snprintf(buf, sizeof(buf),
        "{\"ax\":%.3f,\"ay\":%.3f,\"az\":%.3f,"
        "\"gx\":%.2f,\"gy\":%.2f,\"gz\":%.2f,"
        "\"roll\":%.1f,\"pitch\":%.1f,\"yaw\":%.1f,"
        "\"bat\":%d,\"fc_state\":\"%s\"}",
        imu.ax, imu.ay, imu.az,
        imu.gx, imu.gy, imu.gz,
        roll, pitch, yaw,
        bat, state_str);

    httpd_resp_set_type(req, "application/json");
    httpd_resp_set_hdr(req, "Access-Control-Allow-Origin", "*");
    return httpd_resp_send(req, buf, strlen(buf));
}

/* GET / — main HTML page */
esp_err_t index_handler(httpd_req_t *req) {
    httpd_resp_set_type(req, "text/html");
    httpd_resp_set_hdr(req, "Access-Control-Allow-Origin", "*");
    return httpd_resp_send(req, INDEX_HTML, strlen(INDEX_HTML));
}

/* GET /stream — MJPEG stream */
esp_err_t stream_handler(httpd_req_t *req) {
    camera_fb_t * fb = NULL;
    esp_err_t res = ESP_OK;
    char part_buf[64];

    static int64_t last_frame_time = 0;
    static uint32_t frames = 0;

    res = httpd_resp_set_type(req, _STREAM_CONTENT_TYPE);
    if(res != ESP_OK) return res;

    httpd_resp_set_hdr(req, "Access-Control-Allow-Origin", "*");

    while(true) {
        fb = esp_camera_fb_get();
        if (!fb) {
            ESP_LOGE(TAG, "Camera capture failed");
            res = ESP_FAIL;
        } else {
            frames++;
            int64_t now = esp_timer_get_time();
            if (now - last_frame_time >= 1000000) {
                float fps = (frames * 1000000.0) / (now - last_frame_time);
                printf(">>> STREAMING: %.2f FPS | Res: QVGA\n", fps);
                frames = 0;
                last_frame_time = now;
            }

            size_t hlen = snprintf(part_buf, 64, _STREAM_PART, fb->len);
            res = httpd_resp_send_chunk(req, part_buf, hlen);
            if(res == ESP_OK) res = httpd_resp_send_chunk(req, (const char *)fb->buf, fb->len);
            if(res == ESP_OK) res = httpd_resp_send_chunk(req, _STREAM_BOUNDARY, strlen(_STREAM_BOUNDARY));
            esp_camera_fb_return(fb);
        }
        if(res != ESP_OK) break;
    }
    return res;
}
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
void app_main(void) {
    esp_log_level_set("cam_hal", ESP_LOG_NONE);
    esp_err_t ret = nvs_flash_init();
    if (ret == ESP_ERR_NVS_NO_FREE_PAGES || ret == ESP_ERR_NVS_NEW_VERSION_FOUND) {
        ESP_ERROR_CHECK(nvs_flash_erase());
        ret = nvs_flash_init();
    }
    ESP_ERROR_CHECK(ret);

    ESP_LOGI(TAG, "--- Step 0: Battery Monitor ---");
    bat_adc_init();
    xTaskCreate(battery_task, "battery", 3072, NULL, 3, NULL);

    ESP_LOGI(TAG, "--- Step 1: Flight Controller (IMU + Motors) ---");
    fc_init();

    ESP_LOGI(TAG, "--- Step 2: Camera ---");
    if(init_camera() != ESP_OK) {
        ESP_LOGE(TAG, "Fatal camera error. Restarting in 5s...");
        vTaskDelay(pdMS_TO_TICKS(5000));
        esp_restart();
    }

    vTaskDelay(pdMS_TO_TICKS(2000));

    ESP_LOGI(TAG, "--- Step 3: Wi-Fi AP ---");
    ESP_ERROR_CHECK(esp_netif_init());
    ESP_ERROR_CHECK(esp_event_loop_create_default());
    esp_netif_create_default_wifi_ap();
    wifi_init_config_t cfg = WIFI_INIT_CONFIG_DEFAULT();
    ESP_ERROR_CHECK(esp_wifi_init(&cfg));
    ESP_ERROR_CHECK(esp_event_handler_instance_register(WIFI_EVENT, ESP_EVENT_ANY_ID,
                                                         &event_handler, NULL, NULL));

    wifi_config_t wifi_config = {
        .ap = {
            .ssid           = WIFI_SSID,
            .ssid_len       = strlen(WIFI_SSID),
            .password       = WIFI_PASS,
            .max_connection = 4,
            .authmode       = WIFI_AUTH_WPA2_PSK,
            .channel        = 2,
        },
    };
    ESP_ERROR_CHECK(esp_wifi_set_mode(WIFI_MODE_AP));
    ESP_ERROR_CHECK(esp_wifi_set_config(WIFI_IF_AP, &wifi_config));
    ESP_ERROR_CHECK(esp_wifi_start());
    ESP_LOGI(TAG, "AP started: %s | 192.168.4.1", WIFI_SSID);

    /* Main HTTP server (port 80) */
    httpd_handle_t server = NULL;
    httpd_config_t server_config = HTTPD_DEFAULT_CONFIG();
    server_config.stack_size       = 8192;
    server_config.max_uri_handlers = 10;
    server_config.max_open_sockets = 7;

    if (httpd_start(&server, &server_config) == ESP_OK) {
        httpd_uri_t uri_index   = { .uri="/",        .method=HTTP_GET, .handler=index_handler   };
        httpd_uri_t uri_control = { .uri="/control", .method=HTTP_GET, .handler=control_handler };
        httpd_uri_t uri_imu     = { .uri="/imu",     .method=HTTP_GET, .handler=imu_handler     };
        httpd_uri_t uri_cmd     = { .uri="/cmd",     .method=HTTP_GET, .handler=cmd_handler     };
        httpd_uri_t uri_pid     = { .uri="/pid",     .method=HTTP_GET, .handler=pid_handler     };
        httpd_uri_t uri_ws      = { .uri="/ws",      .method=HTTP_GET, .handler=ws_handler,
                                    .is_websocket=true };
        httpd_register_uri_handler(server, &uri_index);
        httpd_register_uri_handler(server, &uri_control);
        httpd_register_uri_handler(server, &uri_imu);
        httpd_register_uri_handler(server, &uri_cmd);
        httpd_register_uri_handler(server, &uri_pid);
        httpd_register_uri_handler(server, &uri_ws);
    }

    /* Stream server (port 81) — separate server to avoid blocking main */
    httpd_handle_t stream_server = NULL;
    httpd_config_t stream_config = HTTPD_DEFAULT_CONFIG();
    stream_config.server_port    = 81;
    stream_config.ctrl_port      = 32769;
    stream_config.stack_size     = 8192;
    stream_config.max_uri_handlers = 2;
    stream_config.max_open_sockets = 2;

    if (httpd_start(&stream_server, &stream_config) == ESP_OK) {
        httpd_uri_t uri_stream = { .uri="/stream", .method=HTTP_GET, .handler=stream_handler };
        httpd_register_uri_handler(stream_server, &uri_stream);
    }

    ESP_LOGI(TAG, "Server ready — http://192.168.4.1");
}

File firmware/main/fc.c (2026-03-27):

/* ================================================================
 * fc.c — Flight Controller
 *
 * Sensor fusion : Mahony AHRS
 *                 (ported from sensfusion6.c — Crazyflie / ESP-Drone)
 * PID control   : cascade rate / attitude
 *                 (ported from pid.c         — Crazyflie / ESP-Drone)
 * Hardware      : LEDC PWM brushed motors + MPU-6050 @ 500 Hz
 *
 * Adapted from ESP-Drone (Espressif, GPL-3.0)
 *   Copyright 2019-2020 Espressif Systems (Shanghai)
 *   Copyright (C) 2011-2012 Bitcraze AB
 * ================================================================ */

#include "fc.h"

#include <math.h>
#include <stdint.h>
#include <string.h>

#include "freertos/FreeRTOS.h"
#include "freertos/task.h"
#include "freertos/semphr.h"
#include "driver/ledc.h"
#include "driver/i2c_master.h"
#include "driver/gpio.h"
#include "esp_log.h"
#include "esp_timer.h"

static const char *TAG = "FC";

/* ── Motor GPIOs ─────────────────────────────────────────────
 *  M1 front-left  (CW)  | M2 front-right (CCW)
 *  M4 back-left   (CCW) | M3 back-right  (CW)
 * ─────────────────────────────────────────────────────────── */
#define MOTOR_GPIO_M1   2
#define MOTOR_GPIO_M2   3
#define MOTOR_GPIO_M3   4
#define MOTOR_GPIO_M4   7

/* LEDC — TIMER_1 because TIMER_0 is used by the camera XCLK */
#define MOT_SPEED       LEDC_LOW_SPEED_MODE
#define MOT_TIMER       LEDC_TIMER_1
#define MOT_FREQ_HZ     15000
#define MOT_BITS        LEDC_TIMER_8_BIT
#define MOT_MAX_DUTY    255

/* ── IMU (MPU-6050) ──────────────────────────────────────────
 *  Same pins as in the original firmware (GPIO 5 = SCL, 6 = SDA).
 *  fc_init() takes ownership of the I2C bus.
 * ─────────────────────────────────────────────────────────── */
#define IMU_SCL         GPIO_NUM_5
#define IMU_SDA         GPIO_NUM_6
#define MPU_ADDR        0x68

/* MPU-6050 register map (subset) */
#define MPU_PWR_MGMT_1  0x6B
#define MPU_SMPLRT_DIV  0x19
#define MPU_CONFIG_REG  0x1A
#define MPU_GYRO_CFG    0x1B
#define MPU_ACCEL_CFG   0x1C
#define MPU_ACCEL_XOUT  0x3B

/* Full-scale ranges configured in fc_init() */
#define GYRO_SCALE      16.4f    /* ±2000 °/s  → 16.4  LSB/°/s  */
#define ACCEL_SCALE     2048.0f  /* ±16 g       → 2048  LSB/g    */

/* ── Timing ──────────────────────────────────────────────────*/
#define FC_HZ           500
#define FC_DT           (1.0f / FC_HZ)
#define FC_PERIOD_MS    (1000 / FC_HZ)   /* 2 ms                  */
#define FC_WARMUP_S     2                /* seconds before arming */

/* ── Safety ──────────────────────────────────────────────────*/
#define WDT_TIMEOUT_US  500000ULL        /* 500 ms watchdog        */
#define TILT_LIMIT_DEG  50.0f

/* ── Mahony AHRS gains (from sensfusion6.c) ──────────────────*/
#define TWO_KP          (2.0f * 0.4f)
#define TWO_KI          (2.0f * 0.001f)
#define M_PI_F          3.14159265f

/* ================================================================
 * Minimal self-contained PID
 * (algorithm from pid.c — Crazyflie, simplified: no D-filter)
 * ================================================================ */
typedef struct {
    float kp, ki, kd;
    float desired;
    float error, prev_error;
    float integ;
    float i_limit;
    float out_limit;
} pid_t;

static float pid_update(pid_t *p, float measured, float dt)
{
    p->error = p->desired - measured;
    float deriv = (p->error - p->prev_error) / dt;

    p->integ += p->error * dt;
    if (p->i_limit > 0.0f) {
        if (p->integ >  p->i_limit) p->integ =  p->i_limit;
        if (p->integ < -p->i_limit) p->integ = -p->i_limit;
    }

    float out = p->kp * p->error + p->ki * p->integ + p->kd * deriv;
    if (p->out_limit > 0.0f) {
        if (out >  p->out_limit) out =  p->out_limit;
        if (out < -p->out_limit) out = -p->out_limit;
    }

    p->prev_error = p->error;
    return out;
}

static void pid_reset(pid_t *p)
{
    p->error = p->prev_error = p->integ = 0.0f;
}

/* ================================================================
 * Global state
 * ================================================================ */
static volatile fc_state_t  s_state    = FC_DISARMED;
static fc_setpoint_t        s_sp       = {0};
static int64_t              s_last_sp_us = 0;
static SemaphoreHandle_t    s_sp_mutex;

/* Attitude + IMU data shared with HTTP handlers */
static float                s_roll = 0, s_pitch = 0, s_yaw = 0;
static fc_imu_t             s_imu  = {0};
static SemaphoreHandle_t    s_att_mutex;

/* ── Mahony quaternion state (from sensfusion6.c) ──────────── */
static float qw = 1.0f, qx = 0.0f, qy = 0.0f, qz = 0.0f;
static float iFBx = 0.0f, iFBy = 0.0f, iFBz = 0.0f;

/* ── PID controllers ─────────────────────────────────────────
 * Cascade: attitude outer loop → rate inner loop
 * Gains are conservative starting values — tune on the bench.
 * ─────────────────────────────────────────────────────────── */
/* Outer: desired angle (°) → rate setpoint (°/s) */
static pid_t pid_att_roll  = { .kp=3.5f, .ki=2.0f, .kd=0.0f,
                                .i_limit=20.0f, .out_limit=20.0f };
static pid_t pid_att_pitch = { .kp=3.5f, .ki=2.0f, .kd=0.0f,
                                .i_limit=20.0f, .out_limit=20.0f };

/* Inner: desired rate (°/s) → torque output (raw) */
static pid_t pid_rate_roll  = { .kp=70.0f, .ki=0.0f, .kd=0.0f,
                                 .i_limit=33.3f, .out_limit=32767.0f };
static pid_t pid_rate_pitch = { .kp=70.0f, .ki=0.0f, .kd=0.0f,
                                 .i_limit=33.3f, .out_limit=32767.0f };
static pid_t pid_rate_yaw   = { .kp=50.0f, .ki=0.0f, .kd=0.0f,
                                 .i_limit=33.3f, .out_limit=32767.0f };

/* ── I2C handles ─────────────────────────────────────────────*/
static i2c_master_bus_handle_t s_i2c_bus;
static i2c_master_dev_handle_t s_mpu_dev;

/* ================================================================
 * Private helpers
 * ================================================================ */

/* Fast inverse square-root (from sensfusion6.c / Quake III) */
static float inv_sqrt(float x)
{
    float halfx = 0.5f * x;
    float y = x;
    int32_t i;
    memcpy(&i, &y, sizeof(i));
    i = 0x5f3759df - (i >> 1);
    memcpy(&y, &i, sizeof(y));
    y = y * (1.5f - (halfx * y * y));
    return y;
}
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

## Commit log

2026-03-27 Initial commit: drone rPPG firmware + software
    Firmware ESP-IDF (XIAO ESP32-S3 Sense): MJPEG stream, IMU MPU-6050,
    flight controller Mahony AHRS + cascade PID, battery monitor.
    Software Python: MediaPipe FaceMesh, rPPG algorithms (GREEN, OMIT,
    POS_WANG, adaptive LMS with IMU), real-time HR estimation.
2026-03-27 feat: multi-region ROI pipeline + evaluation script
    - ROIExtraction.py: 3 ROI modes (FOREHEAD, FACE, MULTI), face oval
    landmarks, 9x9 grid extraction, DMRS selection (KFD + spectral
    energy), grid overlay visualisation
    - Processor.py: roi parameter, DMRS in background thread (every 90
    frames), camera display restored, selected regions shown in green
    - main.py: startup prompt for ROI mode selection
    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
2026-03-28 feat: respiratory rate mode via Bartula 2013 algorithm
    Adds RespiratoryProcessor — a new operating mode (selectable at startup)
    that estimates breathing rate from video without contact.
    Algorithm (Bartula, IEEE EMBS 2013):
    - MediaPipe Pose runs once at startup to locate the chest ROI from
    shoulder landmarks; Pose is then closed
    - Per frame: 1D vertical profile (mean+std/row, high-pass) →
    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
2026-03-31 feat: add display toggle option (graphs + camera on/off)
    Adds a prompt at startup to choose between full visual mode
    (matplotlib plots + camera window) or terminal-only mode,
    reducing rendering overhead and improving FPS in headless runs.
2026-03-31 docs: update README and SOFTWARE.md for display toggle and validation scripts
    Documents the new display toggle option (graphs + camera on/off),
    the validation/ directory added by collaborator (PPG2csv, Resp2csv,
    Validation_rPPG_PPG, Validation_Resp_Resp, Validation_rPPG_SMARTLOCK,
    SensorIntegration.ino), and updates the status checklist.
2026-03-31 feat: add validity mask to DMRS and switch spectral ranking to SNR
    extract_grid_rgb now returns a (means, valid) tuple; Processor stores
    region_valid per frame and passes a valid_mask to dmrs_select so that
    grid cells filled with the face_mean fallback are excluded from region
    selection. dmrs_select spectral ranking changed from raw band energy to
    band SNR (band_energy / out-of-band_energy) to penalise noisy regions.
2026-04-01 feat: update validation scripts and add recordings
    - PPG2csv: add display toggle, DISPLAY_SECS config, and increase WINDOW_SIZE to 2000
    - Resp2csv: matching updates
    - Add validation recordings (rPPG, LMS, OMIT, POS_WANG, Resp)
    [Recording_Resp_Bartula_1774963842.csv, Recording_Resp_Bartula_1774964376.csv, Recording_rPPG_GREEN_1774967191.csv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]
2026-04-01 refactor: rename validation/ to test/, align GT computation with processors
    - Rename software/validation/ → software/test/
    - Rename recordings/ → data/, run_all.py → RunTest.py,
    evaluate.py → Evaluate.py, plot_signals.py → PlotData.py
    - Remove Validation_*.py and datacleaning.py (superseded)
    - PPG2csv: HR_gt now uses 30s backward window power FFT (no filtering),
    identical to Processor.estimate_hr
    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
    [Recording_Resp_Bartula_1774963842.csv, Recording_Resp_Bartula_1774964376.csv, Recording_rPPG_GREEN_1774967191.csv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]
2026-04-02 feat(evaluate): extend evaluate_rppg_file() with SNR and Accuracy %
    - compute_snr(df) called once before algo loop (file-level signal)
    - accuracy_pct computed per-algo using ACCURACY_BPM_THRESHOLD (5 bpm)
    - snr_mean and accuracy_pct added to metrics dict m
    - print extended to include SNR=X.XXdB and Acc=XX.X% fields
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2026-04-02 fix(evaluate): replace \u00b1 escape with literal ± in f-string (Python 3.11 incompatibility)
    [Evaluate.py]
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2026-04-02 feat(evaluate): filter warmup (t<15s) and remove csv_raw output
    - Skip first 15 s of each recording before any metric/SNR/plot computation
    - Remove save_summary_csv() call — no longer writing results/csv_raw/
    [Evaluate.py]
2026-04-02 feat(evaluate): differentiated warmup cutoff (30s rPPG / 20s resp), real time axis in plots, reduced SNR guard
    - Warmup cutoff split by recording type: 30 s for rPPG (matches FaceProcessor buffer), 20 s for respiratory (matches MIN_SEC=20)
    - Plot time axis now shows actual recording time from t=0 (starts at ~30s or ~20s), not re-zeroed from the cut point
    - SNR duration guard reduced from 30 s to 10 s (cardiac) / 15 s (respiratory) to avoid NaN on shorter post-warmup windows
    - Remove stale csv_raw plots (output moved to plots_eval/)
    - Update SOFTWARE.md and README.md to reflect new evaluation behaviour
    [summary_metrics.csv]
2026-04-02 chore: add hardware/ directory and plots_eval/ evaluation plots
    [rPPG_Drone_hardware.kicad_sch]
2026-04-02 chore: remove hardware/ from tracking (not ready)
    [rPPG_Drone_hardware.kicad_sch]
2026-04-02 feat(hardware): add KiCad schematic and hardware PDF
    [rPPG_Drone_hardware.kicad_sch]
2026-04-04 feat(pipeline): overhaul test pipeline — peak-based metrics, separate HW/SW recording
    rPPG recording:
    - Replace PPG2csv.py with RecordPPG.py: saves BVP_<ALGO>_<ts>_sw.csv and _hw.csv
    separately at their natural sample rates; uses bvp_by_frame to fix repeated-value bug
    Respiration recording:
    - Replace Resp2csv.py with RecordResp.py: saves RESP_<ts>_sw.csv and _hw.csv;
    applies Bartula filter to full signal after recording
    ComputeMetrics (new):
    - Post-processes BVP and RESP pairs from data/ in a single script
    - HR/SDNN/RMSSD computed via peak intervals (60/mean(RRI), min_dist=0.5s)
    - RR/BBI computed via peak intervals (60/mean(BBI), min_dist=1.5s)
    - Growing window from t=0; deduplicatio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
    [BVP_GREEN_1775253369_hw.csv, BVP_GREEN_1775253369_sw.csv, BVP_OMIT_1775254080_hw.csv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]
2026-04-04 refactor(pipeline): strip metric columns from data CSVs, stop overwriting them
    ComputeMetrics no longer writes metrics back to data files — data CSVs
    now hold only timestamp + signal. Metrics are computed in-memory only.
    [BVP_GREEN_1775253369_hw.csv, BVP_GREEN_1775253369_sw.csv, BVP_OMIT_1775254080_hw.csv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]
2026-04-04 refactor: forehead-only ROI, peak-based HR, pipeline overhaul
    - ROIExtraction: remove FACE/MULTI modes, grid, DMRS, KFD, DFA — keep forehead only
    - Processor: remove roi param, ROI_MULTI branches, region buffers, DMRS background thread; switch HR estimation from FFT to find_peaks (consistent with ComputeMetrics)
    - main.py, RecordPPG: remove ROI selection menu, hardcode forehead
    - ComputeMetrics: output to data_processed/, separate SW/HW processed CSVs
    - Evaluate: absorb PlotData, read from data_processed/, MAE±SD only, per-algorithm tables
    - RunTest: remove PlotData step
    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
    [BVP_GREEN_1775253369_hw.csv, BVP_GREEN_1775253369_sw.csv, BVP_GREEN_1775322941_hw.csv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]
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2026-04-06 docs: update README/SOFTWARE.md to current state; fix bandpass to 4 Hz
    - Processor.py: fix apply_filters upper cutoff 2.0 → 4.0 Hz (45–240 bpm)
    - SOFTWARE.md: update Evaluate.py section — 4 output tables, summary CSV,
    plot description; fix apply_filters band to [0.75–4.0 Hz]
    - README.md: update evaluation output to 4 tables matching Evaluate.py
    [BVP_POS_WANG_1775325541_sw_processed.csv]
2026-04-06 fix(evaluate): add Time (s) x-label to all subplots in rPPG and resp plots
    [Evaluate.py]
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2026-04-06 data: add GREEN IMU and LMS recordings with processed metrics
    [BVP_GREEN_1775475989_hw_IMU.csv, BVP_GREEN_1775475989_hw_IMU_processed.csv, BVP_GREEN_1775475989_sw_IMU.csv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]
